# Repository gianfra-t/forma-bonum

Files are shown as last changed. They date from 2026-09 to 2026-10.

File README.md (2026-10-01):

### Forma Bonum: reinforcing 3d printed parts for the professional UAV market.

We explore reinforcing 3d printed parts with small, distributed pultruded carbon fiber elements for its usage as the main method of construction of production-ready UAVs in the medium size category (25 kg - 150 kg AUW).

<p align="center">
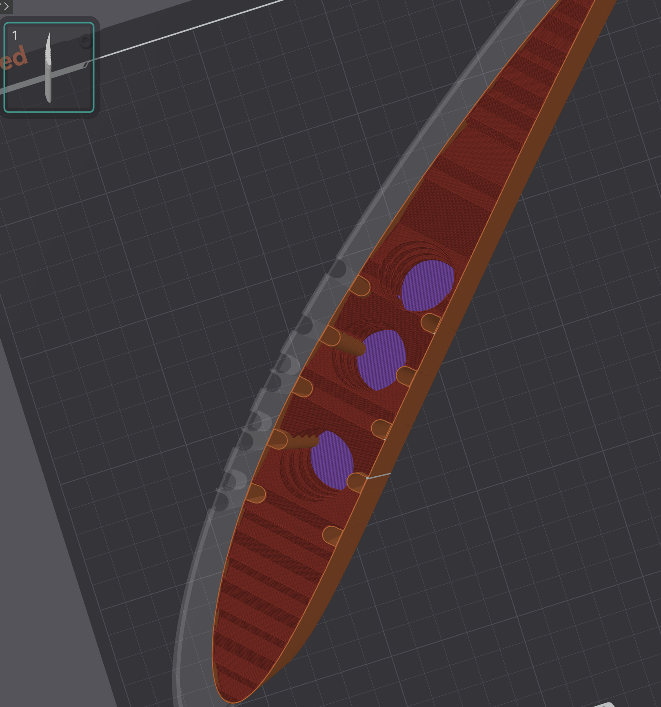
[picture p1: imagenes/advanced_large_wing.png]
  
  <br/>
  <em>sliced wing section with reinforcement channels and optimized infill.</em>
</p>

The following repository acts as storage for all the projects analysis, tests and code. Refer to (summary.md) to learn more about the motivation, rationale and the extended description.

### Index

The repo is organized as follows:

- `wing_assembler` is a python package used to define entire wing sections. It provides reinforcement-placement help relevant for this project, slicing and joinery, and modifiers for each section, ready to add to the slicer of choice.
- `analysis` holds jupyter notebooks running through initial sizing and estimates for the method.
- `tests` has all experiments and material characterizations performed for the project.
- `definitions` are models used for testing or analyses (wing models so far only). Defined using `wing_assembler`.
- `docs`: other miscellaneous documents for the project.

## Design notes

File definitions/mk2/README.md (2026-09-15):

# mk2 — 5/3/1/1 demo panel

NACA 4412 · 1600 mm span · 200→160 mm chord · S 0.288 m² · AR 8.89
20 × 3 mm rods as 5/3/1/1 pairs · four 200 mm print sections · panel ≈ 545 g

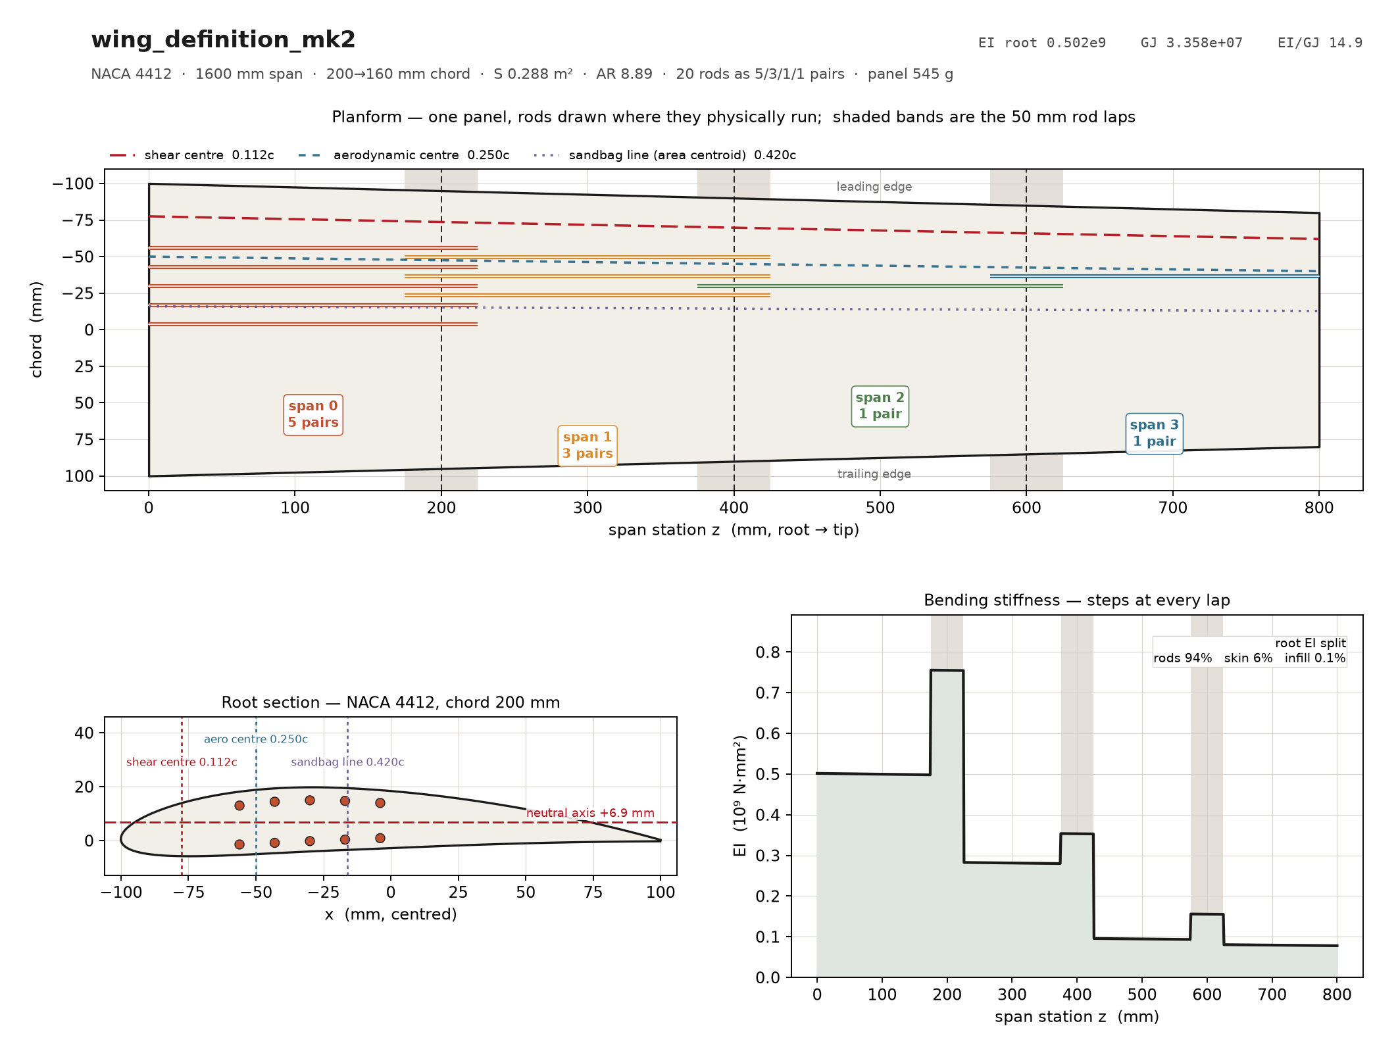
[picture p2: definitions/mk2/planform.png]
planform


Supersedes the mk1 4/3/2/1 layout (`../wing_definition_4321.py`). Same planform,
same rods, same lattice — only the spanwise split changed, because peak rod
stress is at the **root** (117.6 MPa tension / 113.0 compression at n=1, against
46 at the first lap) and mk1 spent pairs outboard where nothing was asking for
them.

WL 100, uniform lift:

| | EI root | rod compr. @n=1 | tip @7 g | first failure | by what |
|---|---|---|---|---|---|
| mk1 4/3/2/1 | 0.406e9 | 134.9 MPa | 186.6 mm | 3.26 g | rod foundation |
| **mk2 5/3/1/1** | **0.502e9** | **113.0 MPa** | **177.1 mm** | **3.78 g** | **wall shear** |

Tip figures include the Timoshenko shear term (10 mm of them). mk2's first
failure is a *shell* mode the rod split cannot move — what the re-split buys is
the rod ladder, 4.59/5.16 g against mk1's 3.84/4.32.

## Regenerate

```bash
cd structures/wing-assembler
python3 analyse.py       definitions/mk2/wing_definition_mk2.py
python3 load_matrix.py   definitions/mk2/wing_definition_mk2.py
python3 plot_planform.py definitions/mk2/wing_definition_mk2.py
wing-assembler definitions/mk2/wing_definition_mk2.py
python3 ../tests/geometry_check.py definitions/mk2/output --chord 200 --span 215
```

## output/

Four print sections, 15 STLs, all **watertight, one solid, inside the station
envelope** (`tests/geometry_check.py`).

| section | z | chord | bores | joints |
|---|---|---|---:|---|
| 00 | 0–200 mm | 200.0 → 190.0 | 8 | root face, male peg |
| 01 | 200–400 | 190.0 → 180.0 | 9 | female + male |
| 02 | 400–600 | 180.0 → 170.0 | 5 | female + male |
| 03 | 600–800 | 170.0 → 160.0 | 2 | female, free tip |

`*_bell_modifier`, `*_rod_joint_modifier` and `*_sleeve_modifier` are **PrusaSlicer
modifier volumes**, not parts. Load them onto the matching `_part.stl` to raise
infill locally; do not print them.

## Print orientation is structural, not a convenience

**Standing on end, span vertical.** Two consequences that the model depends on:

1. The layer plane is the airfoil cross-section, so a rhomboid/diamond infill
   puts struts running **skin to skin** — a stretch-dominated truss rather than a
   bending-dominated foam. That is worth 3.78 g → 5.31 g of first failure
   (`LEARNINGS.md` §4).
2. Nothing printed is continuous along the span; every layer boundary is a
   potential separation. **The rods are the only material that crosses them.**
   Their 94 % of root EI understates their importance — they are also the entire
   spanwise tensile path.

Record the actual infill pattern and density on the build, or neither point can
be checked afterwards.

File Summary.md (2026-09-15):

### TL;DR:

Using 3d printed reinforced parts, I believe we can graudate 3d printing airframes in the UAV market from prototyping into something production-ready, which can be a competitive and cost effective construction method at a fraction of the cost of laminated composites, no special tooling, and yet with competitive performance.

### Abstract

The objective of this is to explore a technique of reinforced 3d printed plastics aimed at production-ready parts for UAVs. 

**It consists of**: A plastic matrix reinforced with several small-diameter pultruded carbon fiber rods. 

<p align="center">
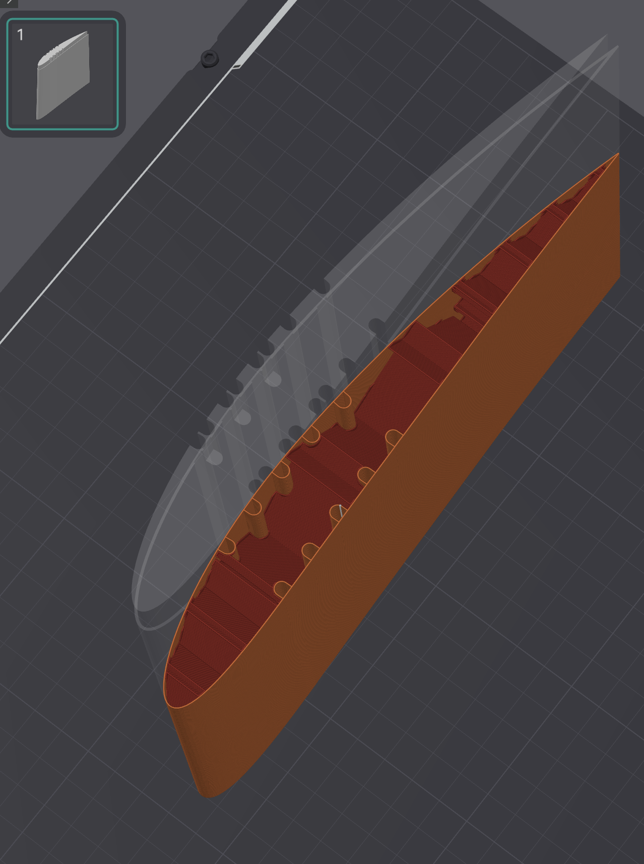
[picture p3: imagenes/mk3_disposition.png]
Latest iteration of rod position and infill
  
  <br>
  <sub><i>Sliced wing section, printed standing on end, with the rod bores running spanwise through it. Latest iteration, optimizing rod position and infill.</i></sub>
</p>

Final geometry ready to fly is made entirely in this manner, and is meant to avoid or reduce as much as possible any form of surface treatment on the part. The philosophy: From printer to flight.

The pieces are made in sections, trying to make as big sections as possible, carbon fiber rods for reinforcement are inserted and glued afterwards. Then the pieces are simply connected with each other. Rods also help as a guide when assembling two sections.

<p align="center">
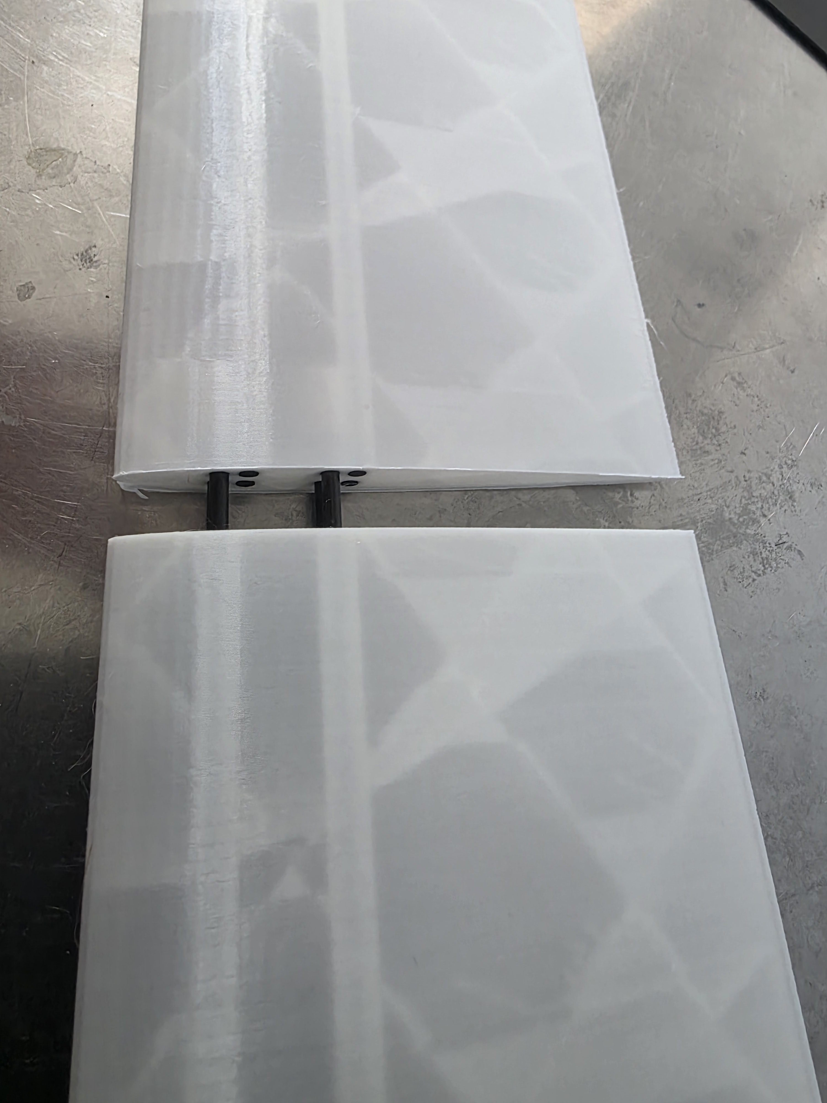
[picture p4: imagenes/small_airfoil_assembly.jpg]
Joining two small airfoil sections for a test
  
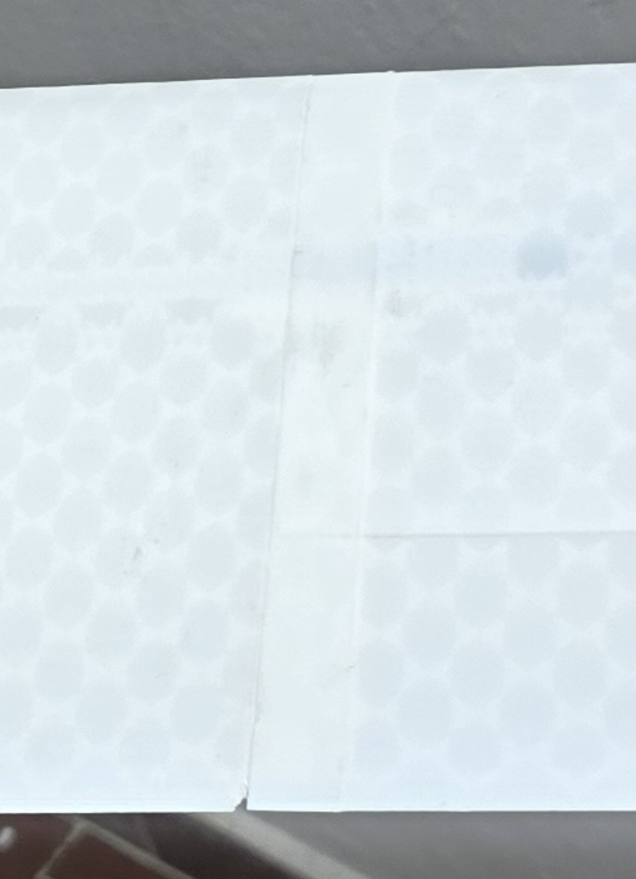
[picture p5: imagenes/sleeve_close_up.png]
join close up
  
  <br>
  <sub><i>Joining two small airfoil sections for a test. Left: illustrative test. Right: section joined using sleeve (male-female) method.</i></sub>
</p>

### Rationale and motivation for the idea

Pultruded carbon rods are produced "en-masse", are standard, easy to source, cheap and can have varying ranges of quality and performance. 
Looking at cross-section of the part, it immediately brings to mind reinforced concrete. 

One of the most common methods to reinforce 3d printed parts for thin profiles like wings is to use a large diameter, hollow carbon fiber tube at the thickest point. The method is simple, but it has some disadvantages in both sourcing the exact diameters and cost of the tube as it grows larger. 
In terms of structures, it has less freedom in how to position the rod/tube to make the most out of the carbon fiber relative to a particular bending or stress direction.

For the case of wings, which is the topic of analysis as it is one of the most demanding elements in terms of material perfomance and weight, this means the rod is positioned near the neutral axis. 

In contrast, a high-end CFRP build (monocoque layout) puts the material mostly in the outer part and alternatively a central spar.

This is in an entirely different league in terms of cost and complexity. A carbon fiber layup is the state of the art but needs to account for layout process and molds, and we require as well a careful design for other failure modes (without getting into details on advanced composite wing making, mostly because I know little about).

The proposed technique goes in a different direction: **Move the reinforcing material as close to the skin as possible, using a large set of small, pultruded rods**.

It leverages the freedom a 3d printer gives us in terms of laying material and complex shapes, which allows to build channels where the rods are inserted. This way, depending on the loads we expect, we can place the rods to reinforce in the perfect spot. 

Some benefits to this tradeoff besides the redistribution of the reinforcement: the load transfer is distributed along a larger relative surface vs one single rod or tube. Therefore have more freedom in placing that reinforcement in the first place. 

It also frees us to build along the z axis, since if we choose to reinforce it, what would be the worse load axis it now becomes the reinforced one. This is specially useful as for aerodynamic shapes it is quite convenient to build with the print axis oriented along the span, for quality reasons.  

And we use the plastic where it's good at: forming the perfect shape for aerodynamic loads, transferring the loads to the reinforced element. This combo provides us with the possibility to easily implement topology optimization, multi-material usage, and complex lattices.

### Positioning on the map: 

It is intended to compete with advanced manufacturing techniques, one or two steps down of state of the art CRPF. 
Although there is much room to improve, initially it is intended to become a better way of manufacturing prototypes, where 3d printing is already the reality for the small UAV world, then move the bar into production for low-mid cost builds.

For designs with low production volumes it is even more interesting as the development of the mold in composites takes out quite a large portion of the cost. It won't ever beat a well crafted, aerospace grade composites part, but it may come close, at a fraction of the cost.

### Enabling technologies:

- Research on high performance 3d printed plastics,
- Large format 3d printers and advanced processes.
- Software enabled designs and optimizations.
- Economics of scale of pultruded carbon elements. 

All 4 things (except for pultruded rods, which we may assume as a standard and settled market) have still room to improve.

### Real world tests

##### Backstory. Initial tests:

So far, tests made are not laboratory grade, but are quite promising. A few initial promising tests that kick off the entire study, showed that the without much care and build effort, and using simply PLA, the rods where the failing element in the reinforced structure. The images and numbers behind that test are worked out in [`tests/experiment-01/ellipse_test.ipynb`](tests/experiment-01/ellipse_test.ipynb).

<p align="center">
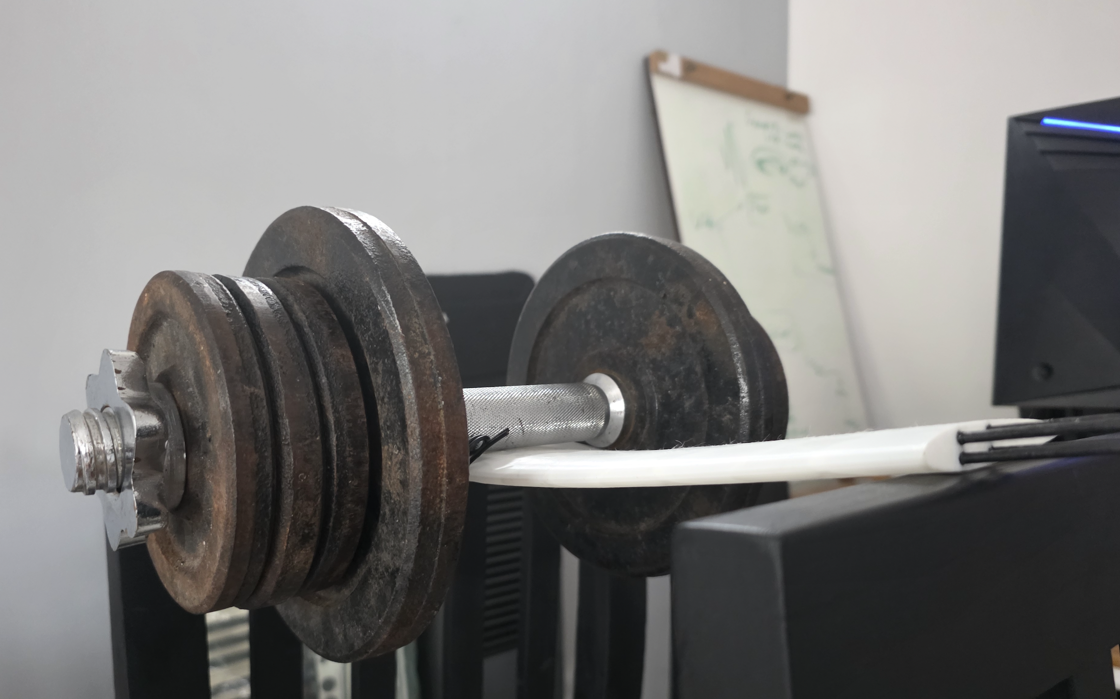
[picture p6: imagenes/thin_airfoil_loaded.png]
Thin airfoil shape reinforced with 2 rod pairs
  
  <br>
  <sub><i>Thin airfoil shape reinforced with 2 pairs of 3mm rods</i></sub>
</p>

This was encouraging, since it means it validated the constructive method and adhesive used. What is even more encouraging was the room for improvement. As I said previously, only standard PLA and infill was used, and for adhesive it's even more homemade: superglue + standard 2 part household epoxy.

#### Wing test and build

The closest test made that is comparable to a real world case so far is that of the **mk2** wing, defined in [`definitions/mk2/`](definitions/mk2/) (NACA 4412, 1600 mm span, 200 → 160 mm chord, 20 × 3 mm rods spent as 5/3/1/1 pairs over four 200 mm printed sections, panel ≈ 545 g). The piece tested below is its two outboard sections, 02 + 03, bonded across their printed joint. 

<p align="center">
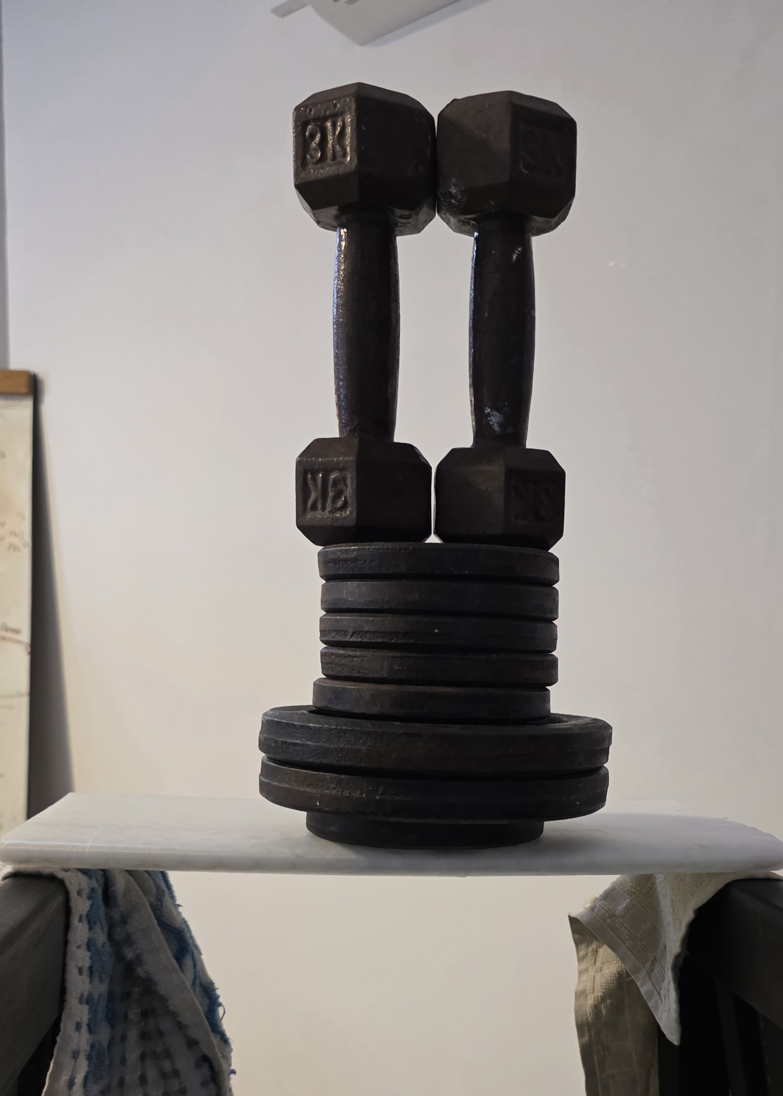
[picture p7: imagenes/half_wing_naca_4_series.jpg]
NACA 4412 half wing on a 3 point bending test
  
  <br>
  <sub><i>Naca 4412, chord 180mm, 1 pair of rod reinforcement. 18 Kg on a 3 point bending test with little deflection and no failure. Total weight less than 200 g</i></sub>
</p>

The motivation for this build was to test against real geometries and loads. Chanzy & Keane (2018), *Analysis and experimental validation of morphing UAV wings*, The Aeronautical Journal 122 (1249), 390–408 ([doi:10.1017/aer.2017.130](https://doi.org/10.1017/aer.2017.130)) is one of the few papers I could find where the wing is weighed once built, and where we know the weight of the aircraft as well. Their aircraft, the Southampton DECODE Mk IV, is a 15 kg MTOW UAV with 2.95 m span, 0.33 m chord and 0.91 m² of wing, built as glass-clad foam over SLS nylon ribs and a carbon spar. The conventional wing weighs 976 g per panel (the paper's "54 g each" makes it per panel, not per wing), so about 1.95 kg for the whole wing, or 13 % of MTOW. That gives us a measured reference for a conventional build in the class this method is aiming at. 

### Models and theory

We have explored in full, so far, 2 models for beam theory on this project: standard beam theory and transformed-section method.

The first method accounts for an analysis of only the rods contributing to stiffness and resistance in bending of the wing. If we want to account for the plastic's share, we must use something like the transformed section method.

- **Rods only, idealized:** [`analysis/idealized_rods_only.ipynb`](analysis/idealized_rods_only.ipynb). The rods are booms carrying all the direct stress, and the plastic is assumed perfect in shear. It is run on the mk2 panel, first as a straight 1 m cantilever and then station by station along the real rod ladder.
- **Transformed section:** [`tests/experiment-01/ellipse_test.ipynb`](tests/experiment-01/ellipse_test.ipynb). $EI$ is summed over rods, wall and infill about the $E$-weighted neutral axis, and calibrated against the 80 kgf ellipse test. 

Both models more than confirm the technique, at least in bending. But much more work needs to be done to explore 3d effects on complex sections like the wing root, wingbox-fuselage attachment, etc. 

Importantly, we also need to verify that the plastic + lattice used in the construction is enough to handle torsion properly to prevent flutter or other undesired effects, since in the proposed reinforcement technique torsion is expected to be handled entirely by the plastic matrix. 

Therefore, a proper FEM model accounting for the rod elements, wall, infill lattice + any other special section, is potentially required to get the most out of this method. Calibrating such a model is no easy feature and requires more empirical tests. which are luckily cheap to perform.

### Software. 

This entire idea relies heavily on software design tooling, particularly due to 2 main factors:

- Choosing many small rods as reinforcement adds complexity on the design and assembly. Ideally not as much complexity as what CFRP requires, but it is definitely a step up in complexity compared to the usage of a single main spar. 

- The freedom we have with 3d printers is large. We can choose to add different densities, different lattices, and even different materials depending on the printer we use. This amount of freedom is almost a "curse", as finding the optimum geometry is not trivial. Many empirical tests and optimization techniques like an adapted topology optimization will be needed to achieve the most of this method.

For the first issue, a good example is what's done in `wing_assembler`. It's basically a seed, but it has prooven already very useful for tests. What this package does, is start from the definition of a wing (given a planform/airfol) and an initial seed of rod positioning, and it returns a ready-to-go set of .stl models, that can be set into the printer's slicer. It basically takes care of modelling the tubes for the rods, adjusting as required, slicing the parts and modelling the lip-joints, and providing a set of modifiers to be used in the slicer where different densities can be selected (as they are the most critical sections)

### Where this technique is relevant (preliminary).

We start to be competitive, as the test (hopefully) shows, on the 10kg empty weight class and above, where the printer can play with the infill densities. We can start playing with 2 walls, different infill lattices and densities, we can position better the rods, etc. 

It is in fact one of the intention of this project is to learn up to which class of aircraft this methodology can be valid. One limiting factor is of course the build size of the printer, assuming printing diagonally on consumer-grade printers we may easily get up to 700mm chords.
For printers with a larger print bed than 500mm, we need to start considering industrial-grade printers.

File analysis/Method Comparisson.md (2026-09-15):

## Method comparisson - Some numbers and cases

How does this method compares with other construction methods out there? Even if we think only of the wing, or airfil-like shapes as the point of reference to answer this question, it is not as simple as one might expect to answer. Definitely not as simple as comparing strenght and Young modulus of the materials used in the comparables. 

First off, we need "hard" data on wings built on this size, just to begin answering the question of "is this method even suitable in terms of strength-to-weight". Then we can start comparing these known design points against our models and tests.

We're taking on the following main datapoints to judge this method so far:
- **Chanzy & Keane (2018)** [1]. The Southampton DECODE Mk IV, a glass-clad foam wing over SLS nylon ribs and a carbon spar. The only wing here that was actually weighed.
- **Keane, Sóbester & Scanlan (2017)** [2], §11.9. SPOTTER, from the same Southampton group and construction family. A very good book, where they present planform and a sandbag load test, but no wing mass or structures breakdown, sadly. But we do get the total weight.
- **Sonkar et al. (2024)** [3]. A fully composite, vacuum-bagged CFRP wing for a 12 kg hybrid VTOL, at 1097 g for the whole wing (≈ 549 g per panel). This figure is stated in the paper, from its laminate sizing table.

All these sources target aircraft sizes of similar MTOW ranges as where this method is supposed to be most useful. In fact, in the lower range of it. Only for two of them we have good data:

| | DECODE Mk IV [1] | SPOTTER [2] | Sonkar VTOL [3] | **mk2 (this project)** |
|---|---|---|---|---|
| Construction | glass-clad foam, SLS nylon ribs, carbon spar | 35 mm CFRP tube spar, foam core, glass/Mylar cover, SLS nylon ribs | moulded CFRP sandwich, vacuum bagged | PLA printed on end, 20 × 3 mm pultruded rods |
| MTOW | 15 kg | 30 kg | ~12 kg | 28.8 kg (design case) |
| Span | 2.95 m | 4.20 m | 2.6 m | 1.6 m |
| Chord | 0.33 m | 0.466 m MAC, rectangular | 0.325 m mean\* | 200 → 160 mm |
| Wing area | 0.91 m² | 1.957 m² | 0.845 m²\* | 0.288 m² |
| Aspect ratio | 9 | 9.0\* | 8 | 8.9 |
| Wing loading | 16.5 kg/m²\* | 16.4 kg/m² | 15 kg/m² | 100 kg/m² (design) |
| Limit load factor | 3.8 (wings designed to 5 g) | 3.8 | not published | — |
| **Wing mass, per panel** | **976 g**, weighed | not published | **~549 g**, stated in the paper | **~450 g**, as built (545 g in the definition) |
| Wing mass, whole wing | 1952 g | not published | 1097 g | ~900 g |
| Wing mass / MTOW | 13.0 % | — | 9.1 % | 3.1 % of the design case |
| Root bending moment per panel, 1 g, uniform lift | 54 N·m\* | 154 N·m\* | 38 N·m\* | 56.5 N·m ([cantilever test](tests/experiment-02/wing_load_failed.ipynb)) |
| Structural test | none (wind tunnel and flight only) | sandbag, ~100 kg per wing (≈ 6.7 g). "The foam parts of the wing failed before the carbon spar" | coupons only, flight tested | sections 02 + 03 held 18 kgf in 3-point bending ([joint test](tests/experiment-03/mk2_joint_test.ipynb)); half-wing cantilever test failed early ([cantilever test](tests/experiment-02/wing_load_failed.ipynb)) |

<sub>\* derived and assumed, not published: DECODE wing loading = MTOW / area; SPOTTER AR = b²/S; Sonkar area = b²/AR and mean chord = S/b. SPOTTER values are the book's concept design (Tables 11.14–11.17); the as-built aircraft is 3.92 m / 34.5 kg. mk2's 28.8 kg is its 0.288 m² at the 100 kg/m² design loading used in the [cantilever test](tests/experiment-02/wing_load_failed.ipynb). Root moments are M = (MTOW/2)·g·(b/2)/2, the same uniform-lift assumption as there, ignoring the fuselage.</sub>

This leads us to the mk2 build ([mk2 definition](definitions/mk2/), load tested in the [cantilever test](tests/experiment-02/wing_load_failed.ipynb)).
It is the intention to build a wing that can carry comparative loads at similar structure weights. And although the planform is smaller on our demo wing, it is still a realistic aircraft. 

Important note: For those paying attention to the demo wing definition, you may notice the wing loading is quite larger than what the design points have. This was a combination of ambitious expectations for the demo, and a restriction about the amount of material (filament, reinforcement) that was around at the time. 

Our build for the demo wing tells us the entiere half wing weighted around 450g. This "would" put the wing at the level of Sonkar et al. [3] (~549 g per panel), and half what is presented in Chanzy & Keane [1] for the DECODE Mk IV aircraft (976 g per panel), but at almost double the loads. It simply was very ambitious demo.

The point is not the mass per panel on its own. The intention is to show that, at least analytically, the mk2 wing would resist as much total load as these wings, and at a smaller weight. In bending. At its 100 kg/m² design loading a mk2 half wing carries 14.4 kg at 1 g, and its root sees 56.5 N·m ([cantilever test](tests/experiment-02/wing_load_failed.ipynb)): the same bending moment as a DECODE Mk IV panel at 1 g (54 N·m), on a 200 mm chord instead of 330 mm. Meaning that even if the demo failed, we have an extra half a kilo per panel, against a conventional foam wing, to play with plastic density and to add more rods, and this is still using PLA. 

Against a moulded CFRP wing like Sonkar's [3] that margin shrinks to about 100 g, but that comparison is not like for like either: Sonkar's aircraft is lighter (~12 kg MTOW) and its panel sees about two-thirds of mk2's root bending moment at 1 g (38 against 56.5 N·m). Its 549 g is also stated in the paper rather than weighed. So at least analytically, with a higher wing loading on a similar aircraft, it is looking in the right direction.

The analytical margin still has to be closed at ultimate load: mk2's first predicted failure is wall shear at 3.78 g (≈ 214 N·m) ([mk2 definition](definitions/mk2/)), against the 5 g (≈ 272 N·m) the DECODE wings were designed to [1]. That is where the difference in weight and the larger structure will probably make a difference.

#### Area scaling

Mass scale linearly with wing area in this method. As volume increases with chord size, internal infill can be removed with cuts and still hold the skin. And again, this is before going to a plastic that will have at least double the modulus of PLA.

The rods already carry most of the bending, so a stiffer plastic changes the bending picture little. Where it counts is the skin, which is where the initial wing failed: a thin printed skin is lost by buckling or wrinkling, and its buckling stress rises roughly in proportion to the plastic's modulus.

Adding rods is cheap and covers bending; a better plastic covers the skin and infill density. Neither requires large reworking the method.

<p align="center">
  Circular infill cuts and bore wall on a large-chord section
  <br>
  <sub><i>Circular infill cuts and bore wall on a large-chord section</i></sub>
</p>

Just to get an idea of the weights without a very large redesign, scaling one of the root sections of the demo wing by 50%, and therefore approaching areas closer to those used in the references, brings that root panel to 194 g of plastic, probably ~220 g with rods included. The entire half-wing would then be closer to 1 kg, as expected (plastic weight calculated by the slicer).

Clearly the demo could not prove this is feasible but as the analysis in the [rods-only model](analysis/idealized_rods_only.ipynb) and the [cantilever test](tests/experiment-02/wing_load_failed.ipynb) showcases, and as the models tell us, it should be possible after a redisgn and choosing the final plastic, at comparative weights. At least, if we consider bending that is. 

### References

1. Chanzy, Q., Keane, A.J. (2018). *Analysis and experimental validation of morphing UAV wings*. The Aeronautical Journal 122 (1249), 390–408. [doi:10.1017/aer.2017.130](https://doi.org/10.1017/aer.2017.130). Open access. Table 1 (aircraft), Table 4 (wing masses). Table 4 gives masses per panel: the conclusions state the morphing wings "weigh only 54 g each more", and 1030 − 976 = 54.
2. Keane, A.J., Sóbester, A., Scanlan, J.P. (2017). *Small Unmanned Fixed-wing Aircraft Design: A Practical Approach*. Wiley. ISBN 978-1-119-40629-7. §11.9 "A Twin Tractor Design: SPOTTER" (Tables 11.14, 11.16, 11.17); Ch. 3, Fig. 3.5 (sandbag test).
3. Sonkar, S., Kumar, P., George, R.C., Yuvaraj, T.P., Philip, D., Ghosh, A.K. (2024). *Low-cost development of a fully composite fixed-wing hybrid VTOL UAV*. Journal of the Brazilian Society of Mechanical Sciences and Engineering 46 (4), 252. [doi:10.1007/s40430-024-04785-2](https://doi.org/10.1007/s40430-024-04785-2). Open access. Table 1 (aircraft), Table 4 (laminate trade study, wing weight).

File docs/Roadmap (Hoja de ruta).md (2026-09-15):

### Promissing directions

- Better plastics: PLA is of course never the final intended plastic, especially for external skin. 
I believe it is still good to prototype and test with it, given that a reinforced engineering plastic is a matter of small recalibration, but we get the same orthotropic properties we struggled with PLA (z direction lower). Meaning, designing and testing with PLA is in the same direction as doing so with a better plastic. 
- Better pultruded elements: from more reputable sources, calibrated and tested. More premium elements would also be a drop-in replacement with large benefits and no re-design effort.
- Exploring pultruded elements that are smaller in diameter (1mm for example) could also unlock reinforcement of more complex 3D shapes, inserting the elements in bended channels.
- Topology optimization: Results from topology optimization can unlock the full potential of the idea. Already `definitions/mk3` uses a set of vertical walls along the span that resemble a torsion box and is in fact a result from using SIMP on a wing under pure torsion.

### Potentiall pitfalls

- The most important one: Fatigue. It is unclear how the plastics will behabe under fatigue loads and even if the rods can provide some interlayer pinning, for wings, plastic must handle entirely on it's own the torsional stresses. 
Since the entire premise of the idea states that this structures are competitive production-wise, it means fatigue loads must be tested accordinlgy for many cycles.

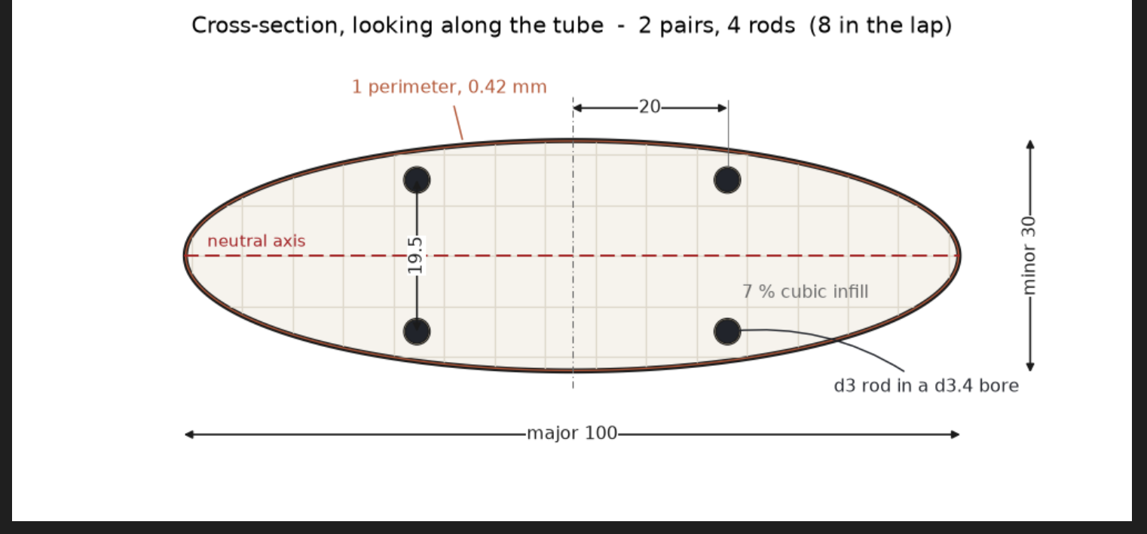
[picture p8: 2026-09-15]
imagenes/ellipse-cross-section.png

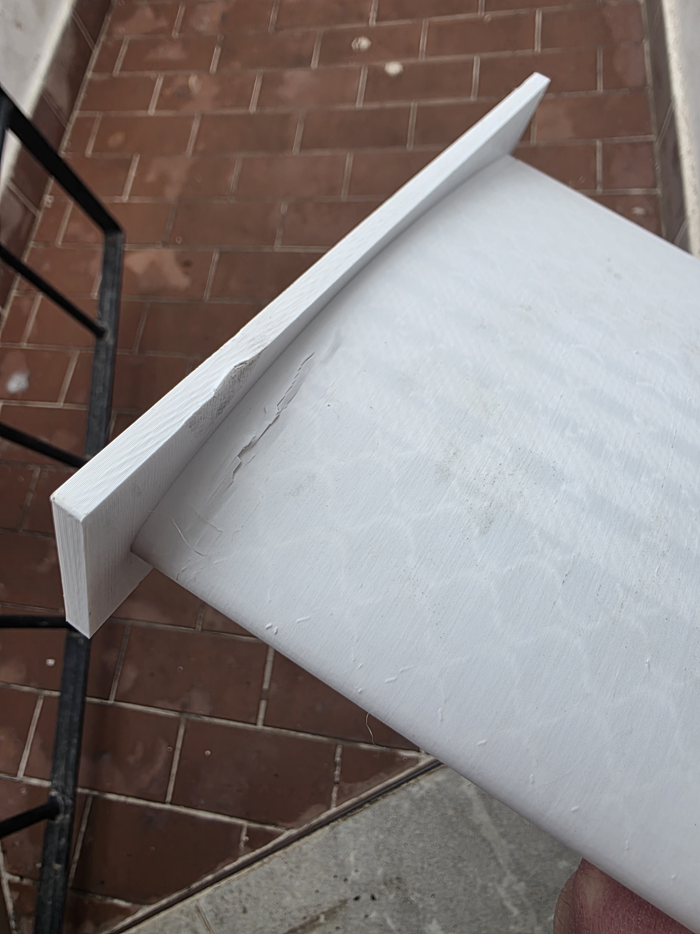
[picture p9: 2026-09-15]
imagenes/failed_wrinkle_skin.jpg

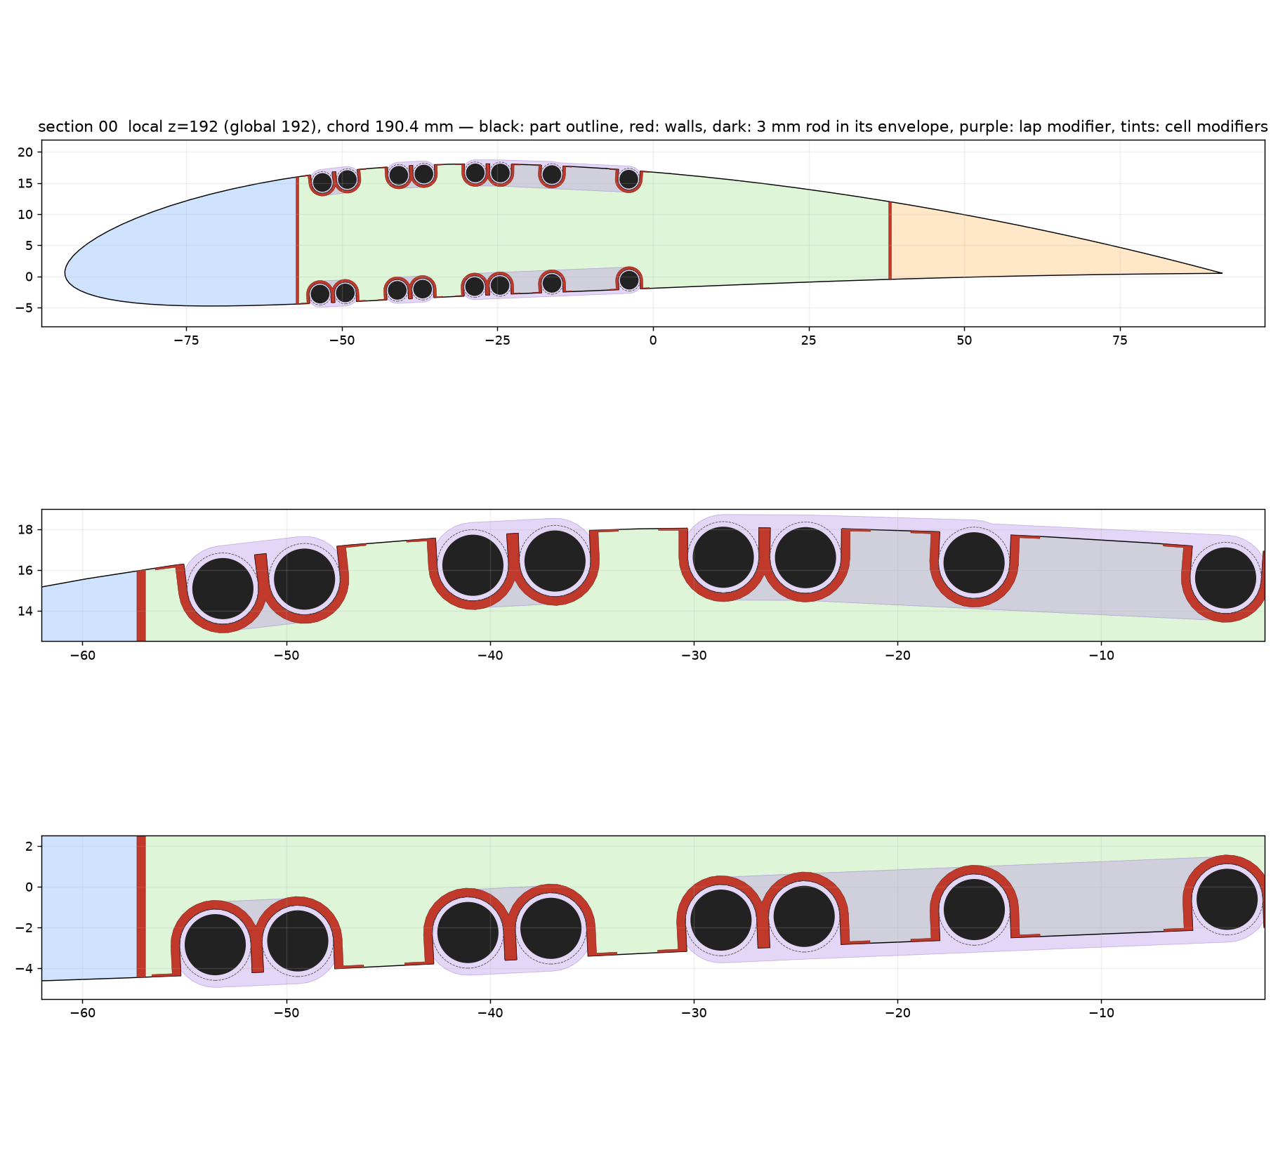
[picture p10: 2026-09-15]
definitions/mk3/cross_section_lap_z192.png

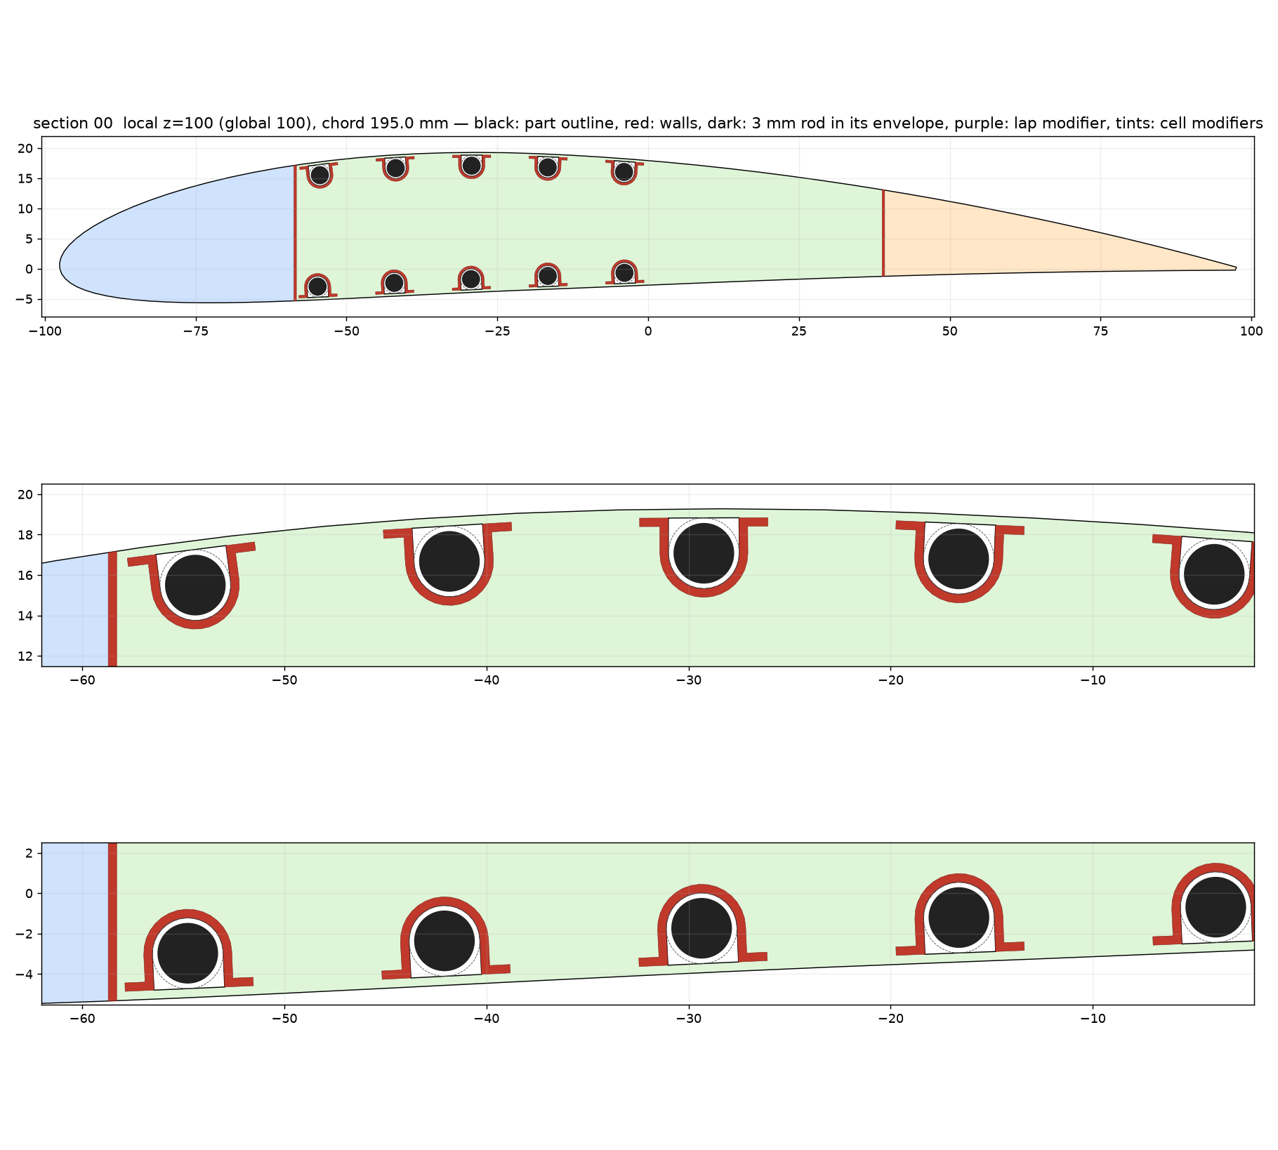
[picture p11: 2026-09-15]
definitions/mk3/cross_section_z100.png

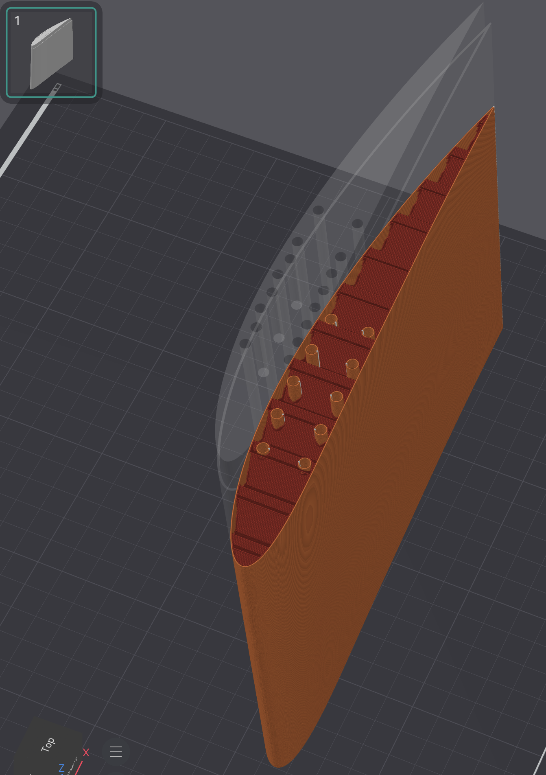
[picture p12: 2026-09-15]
imagenes/airfoil_reinforced_example.png

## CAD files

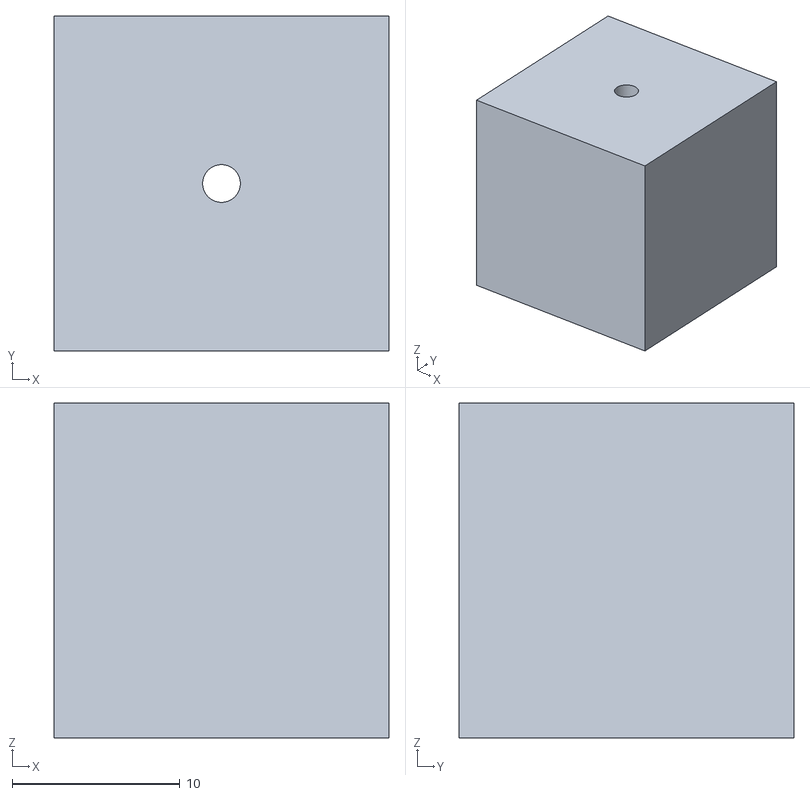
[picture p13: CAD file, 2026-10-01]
definitions/cube_test/output/cube_hole_2.25.stl
20.0 x 20.0 x 20.0

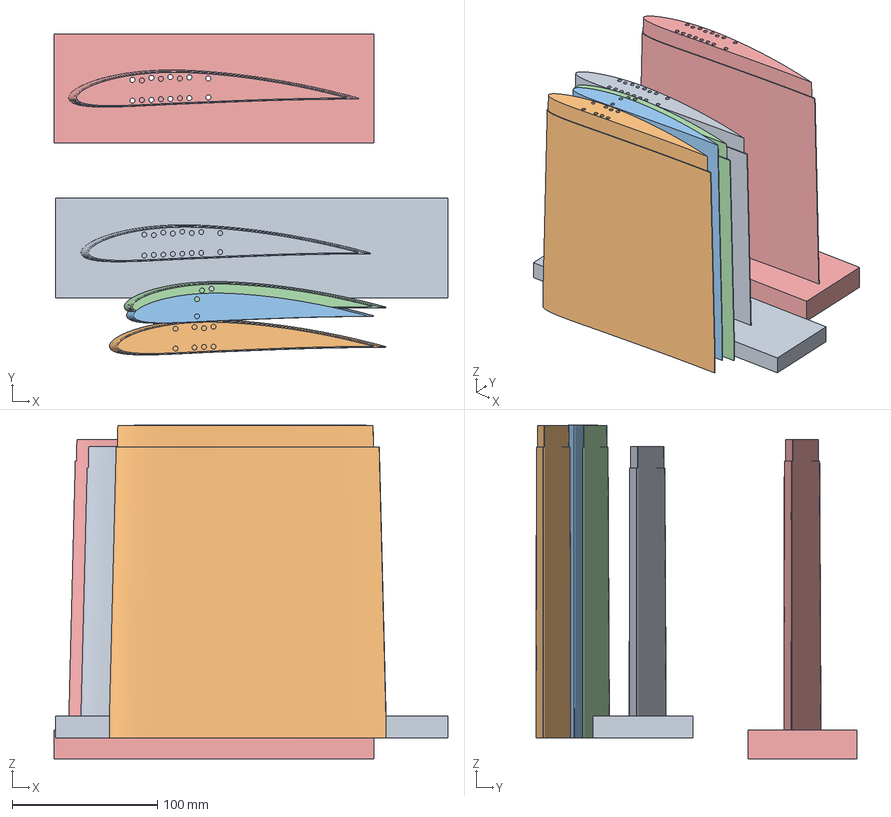
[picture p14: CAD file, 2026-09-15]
definitions/mk2/best-01.3mf
270.9 x 220.7 x 229.5 mm
section_00_part.stl
section_01_part.stl
section_03_part.stl
section_02_part.stl
section_00_part_with_root_plate.stl

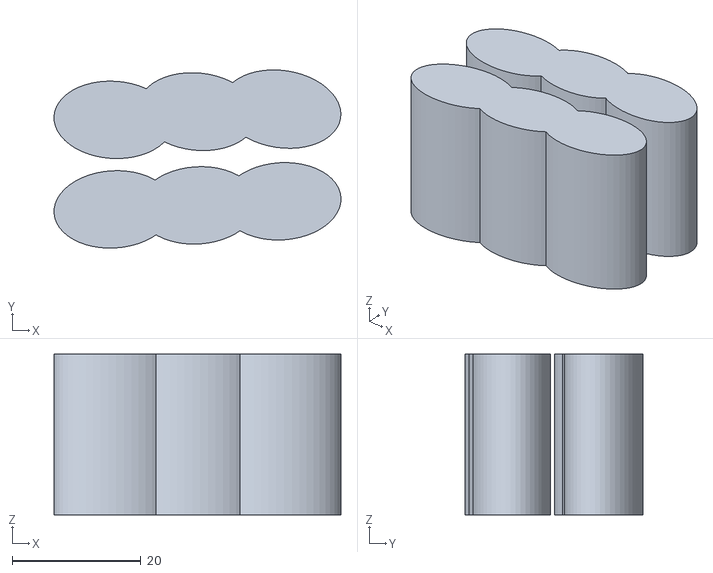
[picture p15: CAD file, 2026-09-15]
definitions/mk2/output/section_00_rod_joint_modifier.stl
44.6 x 27.7 x 25.0

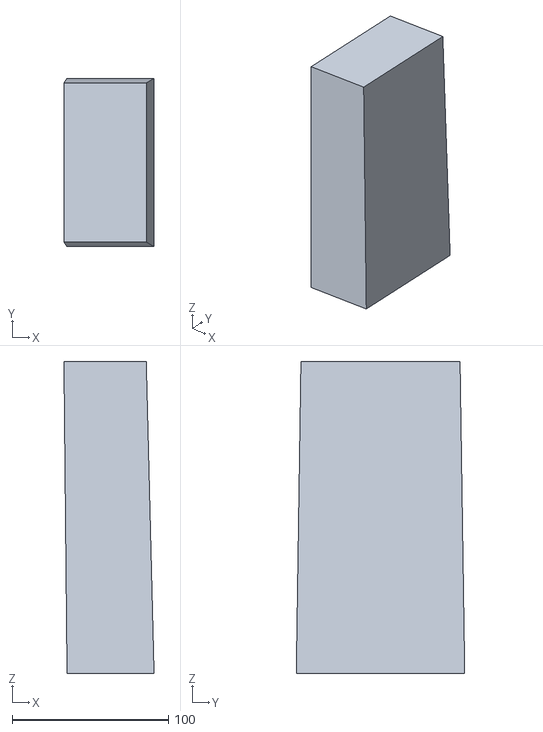
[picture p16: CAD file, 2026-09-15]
definitions/mk3/output/section_02_te_cell_modifier.stl
57.8 x 108.0 x 200.0

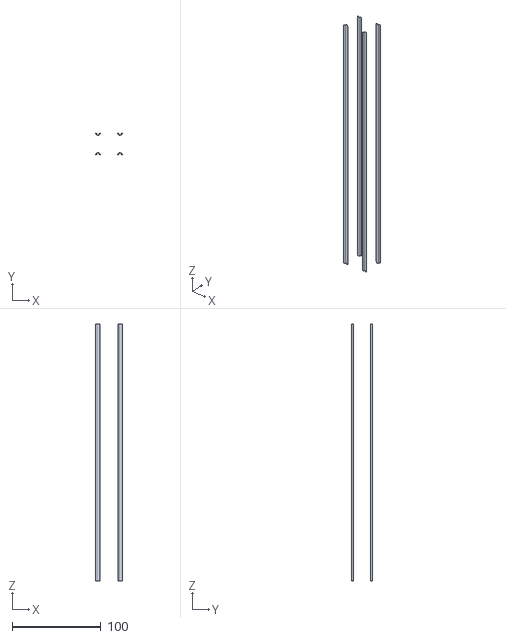
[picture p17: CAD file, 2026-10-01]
definitions/wire_test/output/section_00_walls.stl
30.0 x 24.1 x 290.0

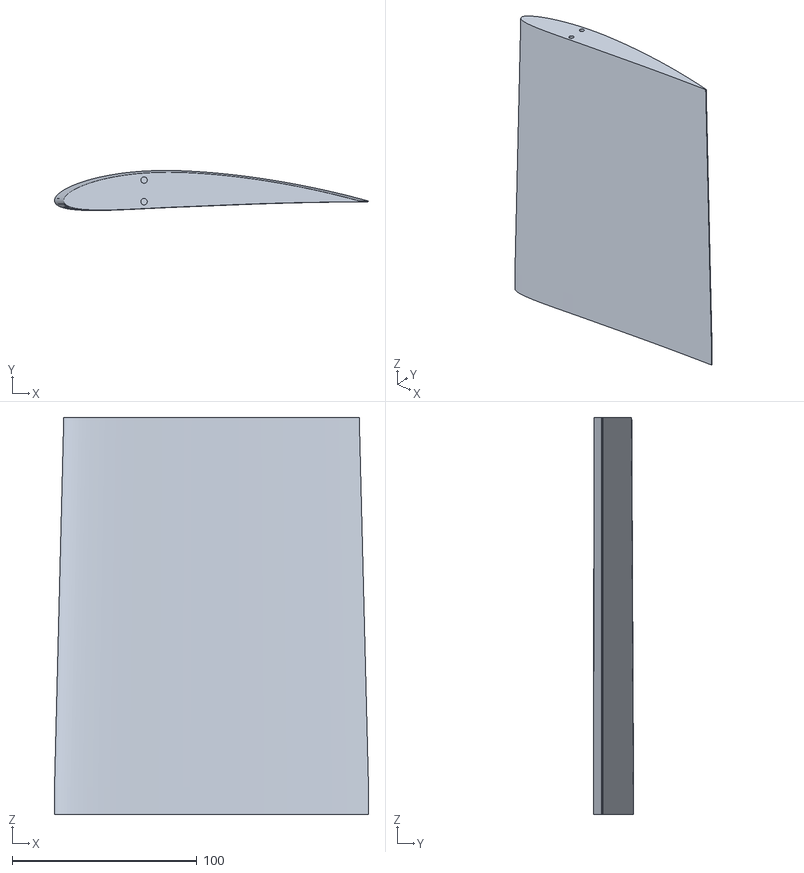
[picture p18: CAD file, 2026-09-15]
definitions/mk2/output/section_03_part.stl
170.1 x 21.7 x 215.0

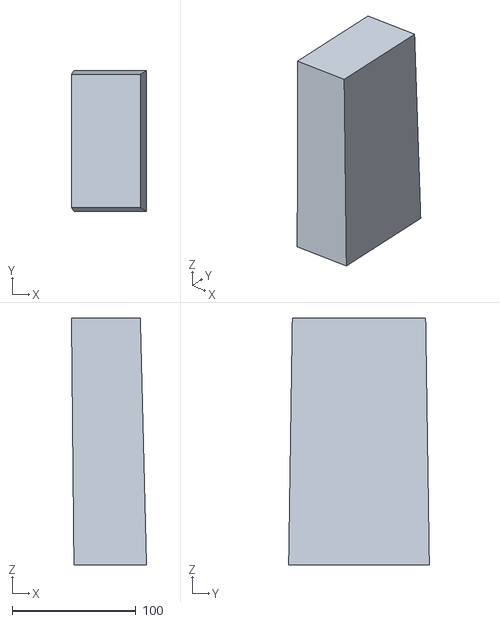
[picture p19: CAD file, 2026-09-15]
definitions/mk3/output/section_01_te_cell_modifier.stl
60.8 x 114.0 x 200.0

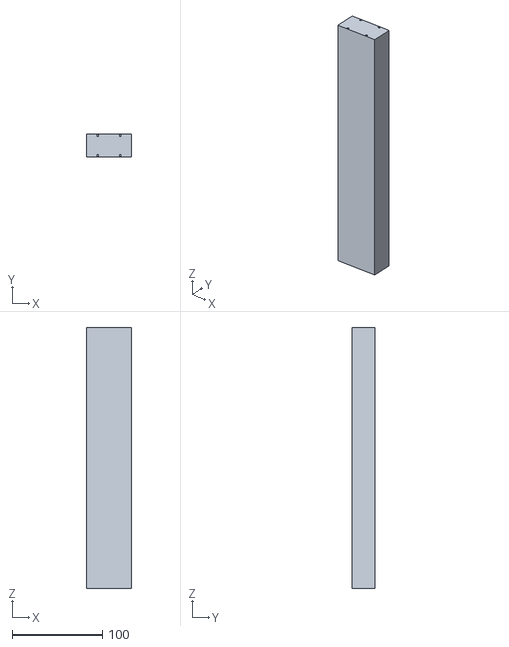
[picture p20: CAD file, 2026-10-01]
definitions/wire_test/output/section_00_part.stl
50.0 x 25.0 x 290.0

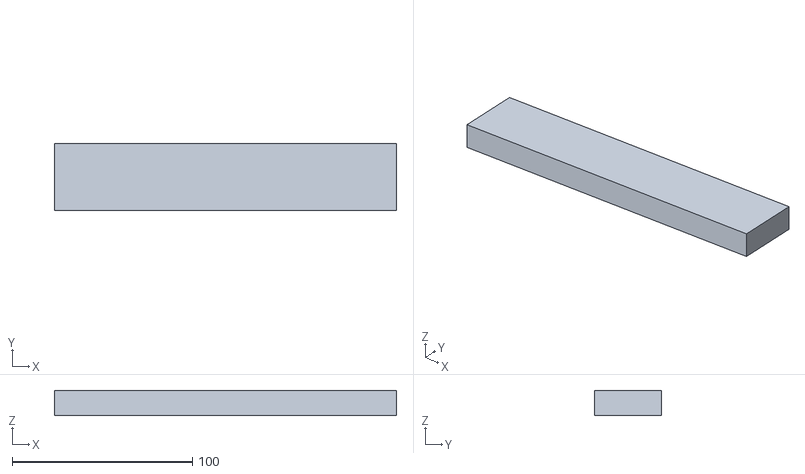
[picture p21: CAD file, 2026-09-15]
definitions/mk2/output/section_02_sleeve_modifier.stl
190.0 x 37.0 x 14.0

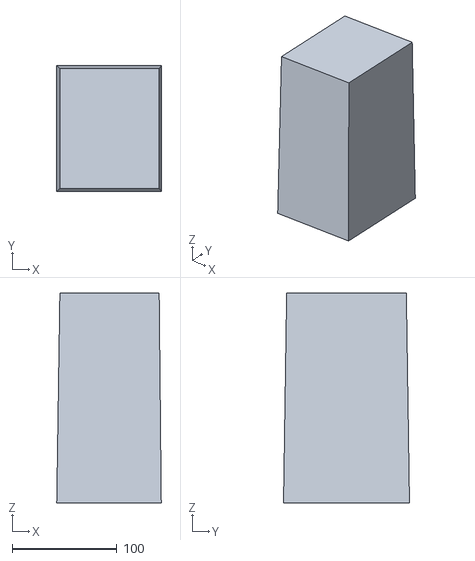
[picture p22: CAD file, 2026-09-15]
definitions/mk3/output/section_00_box_cell_modifier.stl
99.6 x 120.0 x 200.0

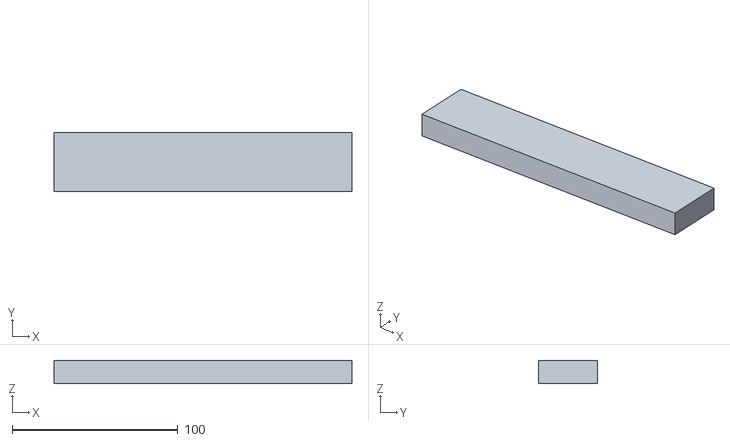
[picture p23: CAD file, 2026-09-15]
definitions/mk2/output/section_03_sleeve_modifier.stl
180.0 x 35.5 x 14.0

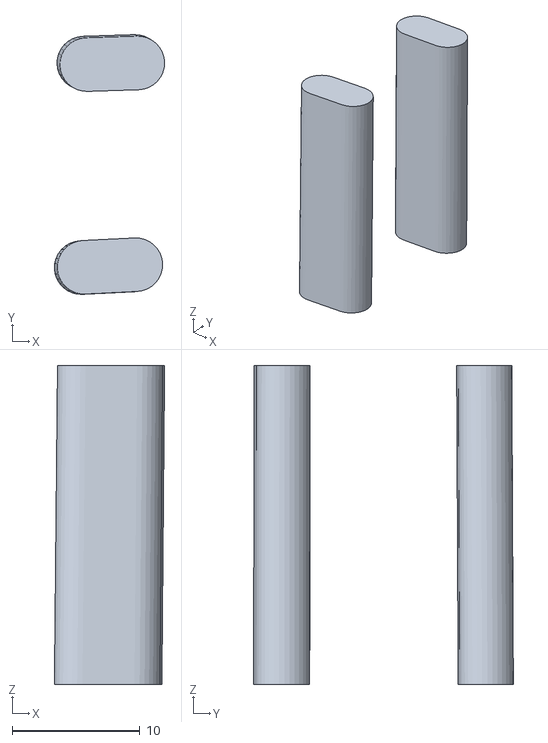
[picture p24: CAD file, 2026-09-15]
definitions/mk3/output/section_03_rod_joint_modifier.stl
8.64 x 20.4 x 25.0

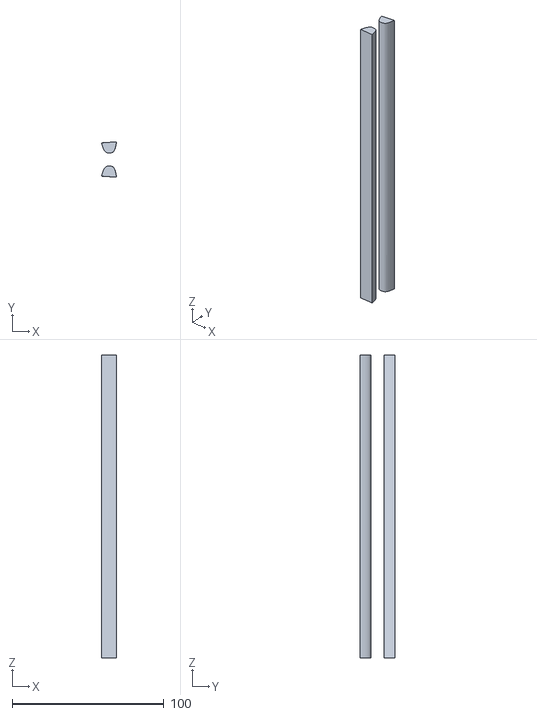
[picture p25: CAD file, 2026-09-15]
definitions/mk2/output/section_03_bell_modifier.stl
10.0 x 23.4 x 200.0

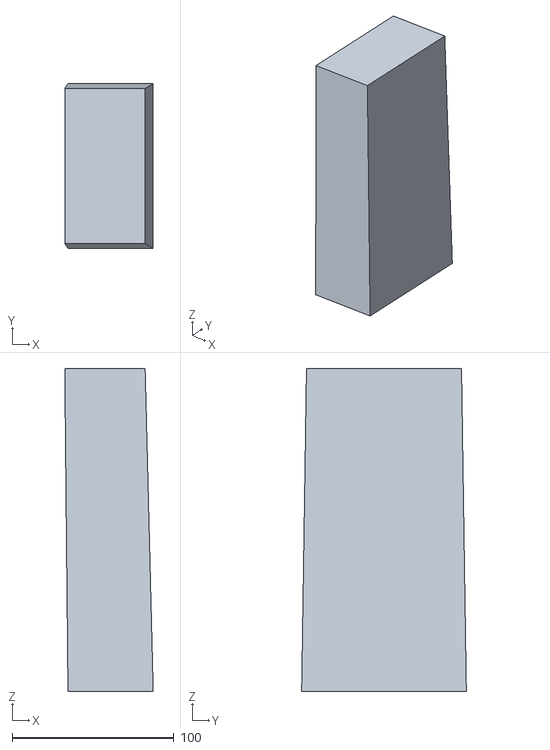
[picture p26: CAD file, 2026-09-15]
definitions/mk3/output/section_03_te_cell_modifier.stl
54.8 x 102.0 x 200.0

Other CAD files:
definitions/cube_test/output/cube_hole_2.15.stl
definitions/cube_test/output/cube_hole_2.10.stl
definitions/cube_test/output/cube_hole_2.00.stl
definitions/cube_test/output/cube_hole_2.30.stl
definitions/cube_test/output/cube_hole_2.05.stl
definitions/cube_test/output/cube_hole_2.20.stl
definitions/mk2/output/section_00_bell_modifier.stl
definitions/mk2/output/section_00_part.stl
definitions/mk2/output/section_00_part_with_root_plate.stl
definitions/mk2/output/section_01_bell_modifier.stl
definitions/mk2/output/section_01_part.stl
definitions/mk2/output/section_01_rod_joint_modifier.stl
definitions/mk2/output/section_01_sleeve_modifier.stl
definitions/mk2/output/section_02_bell_modifier.stl
definitions/mk2/output/section_02_part.stl
definitions/mk2/output/section_02_rod_joint_modifier.stl
definitions/mk2/output/section_03_rod_joint_modifier.stl
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

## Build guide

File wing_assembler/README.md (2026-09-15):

# wing_assembler

Definition in, printable wing STLs out.

## Install

```bash
pip install -e .
```

## Use

Write a definition — a `.py` exposing a module-level `wing`:

```python
from wing_assembler import WingDefinition, RodSection

wing = WingDefinition(
    span=800.0, root_chord=200.0, tip_chord=160.0, naca="4412",
    rod_length=250.0, rod_multiple=1, rod_overlap_pct=0.10,
    rod_diameter=3.4, skin_distance=2.0,
    joint_length=15.0, joint_thickness=0.45,
    clearance=0.0, epoxy_gap=0.3, axial_gap=0.3,
    rod_sections=[                       # the rod ladder, root -> tip
        RodSection(chord_pcts=[0.33, 0.285, 0.375, 0.30, 0.35]),
        RodSection(chord_pcts=[0.348, 0.302, 0.32]),
        RodSection(chord_pcts=[0.34]),
        RodSection(chord_pcts=[0.31]),
    ],
    min_x_separation_pct=0.25, min_y_separation_pct=0.8,
    bell_width=10.0, bell_height=7.0, bell_offset=-1.5, bell_shape=3.5,
    joint_mod_thickness=12.0,
)
```

Each `chord_pcts` entry is an **upper + a lower rod** — one pair, at that
fraction of chord. 

To generate the models:

```bash
wing-assembler path/to/wing_definition.py            # -> path/to/output/
wing-assembler path/to/def.py --out /tmp/w --sections 0,1
```

Per print section it writes:

| file | what |
|---|---|
| `section_NN_part.stl` | the part to print |
| `section_NN_bell_modifier.stl` | infill modifier around full-run bores |
| `section_NN_rod_joint_modifier.stl` | infill modifier across each rod lap |
| `section_NN_sleeve_modifier.stl` | infill modifier in the sleeve zone (female sections) |

The three `*_modifier` STLs are **OrcaSlicer modifier volumes, not parts**.
Load them onto the matching `_part.stl` to raise infill locally. Do not print
them.

## Omega construction

`construction="omega"` is a second way to hold the rods. Every rod pair is
placed tangent to the inside of the skin, and each rod is held by an
omega-shaped wall (one line) with feet on the skin. This shape may bring resamblance to a stringer, in traditional wing structures.

Then, spanwise front and rear webs close a torsion box (although, slightly larger than what a traditional torsion box looks like).

```python
from wing_assembler import WingDefinition, RodSection, OmegaSettings

wing = WingDefinition(
    ...,                                   # as above
    construction="omega",
    omega=OmegaSettings(
        line_width=0.42,                   # every wall is a multiple of this
        skin_lines=1, omega_lines=1, box_wall_lines=1,
        omega_clearance=0.0,               # rod envelope -> clip inner face
        omega_neck_width=None,             # clip legs leave the skin at this width (None = rod_diameter)
        omega_foot_length=1.0,             # foot beyond the clip's outer face
        rod_min_gap=0.5,                   # rod surface to rod surface
        snap_to_previous=True,
        joint_mod_margin_pct=0.20,         # lap modifier: both rods at 1.2 x diameter + the gap
        box_le_pct=0.20, box_te_pct=0.30,  # webs at 20 % from LE and 30 % from TE
    ),
)
```

What changes against the default `"bore"` mode:

* **Rods run straight at a constant x/c, tangent to the skin.** The taper
  tilts them slightly, which is intended. They bear at
  `max(skin_wall, joint_thickness)` below the surface, so they also clear the
  joint sleeve.
* **Placement.** Span 0 is the master and is never moved (a collision raises).
  Each later rod is snapped to `rod_min_gap` beside the nearest rod of the
  previous span, so lapping rods share one clip. If that spot is taken the
  solver tries the other side, then the next inboard rod. After that it
  relaxes to the nearest free spot to the request, also keeping the clip off
  the webs. `print_layout` reports where every rod went.
* **Outputs:** `part` (body with omega pockets), `walls` (clips + webs),
  `le_cell_modifier` / `box_cell_modifier` / `te_cell_modifier`,
  `rod_joint_modifier` (capsules), `sleeve_modifier`. There is no bell modifier.

See `definitions/mk3/` for a worked build and how the walls reach the slicer.

## As a library

```python
from wing_assembler import compute_section_layout, build_all
from wing_assembler.generate import load_definition

wing = load_definition(Path("wing_definition.py"))
for sec in compute_section_layout(wing):
    geom = build_all(sec, wing)     # {'part', 'bell_modifier', ...}
```

## Airfoils

4-digit NACA is computed. Anything else is read from `airfoils/<name>.dat`
(Selig format), and fetched from airfoiltools.com into that directory on first
use.

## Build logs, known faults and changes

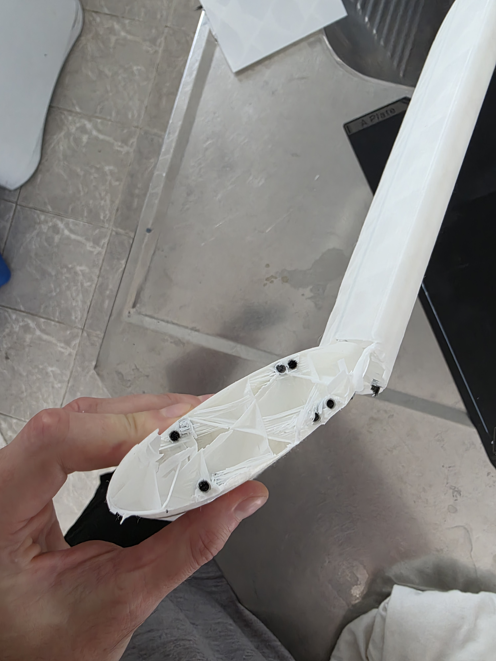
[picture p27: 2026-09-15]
imagenes/ellipse_post_failure.jpg

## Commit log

2026-09-16 wing_assembler: add the topopt modifier render target
    Ported from ConAero, where it was added to the pre-extraction builder by
    88ce48e and left importing naca/section_layout after those modules moved
    here. It belongs with the builder, not with the analysis side.
    build_all takes an optional `patches` and emits a `topopt_modifier` compound
    of box volumes over the topology-optimized chordwise patches; generate picks
    it up from the result dict and writes section_NN_topopt_modifier.stl. The
    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
2026-10-01 add more test shapes and coupons to improve model validity
    [cube_hole_2.00.stl, cube_hole_2.05.stl, cube_hole_2.10.stl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]
